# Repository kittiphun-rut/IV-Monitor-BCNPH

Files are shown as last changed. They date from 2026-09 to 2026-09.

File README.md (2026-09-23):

# IV-Monitor-BCNPH

ซอฟต์แวร์ของโครงการนวัตกรรม **Smart IV Alert** — ระบบตรวจวัดและแจ้งเตือนการให้สารน้ำทางหลอดเลือดดำ
(หอผู้ป่วยอายุรกรรม โรงพยาบาลสูงเม่น จังหวัดแพร่ / วิทยาลัยพยาบาลบรมราชชนนี แพร่)

## โครงสร้างที่เก็บ

เฟิร์มแวร์เก็บเป็น **โฟลเดอร์ชื่อคงที่สายละหนึ่ง** เลขเวอร์ชันอยู่ใน `#define APP_VERSION`
เวอร์ชันเก่าทุกตัวดูได้จาก [`VERSIONS.md`](VERSIONS.md) ซึ่งมีลิงก์โหลด zip ของทุกรุ่น

| ที่อยู่ | คำอธิบาย |
|---|---|
| `firmware/Station/` | **เฟิร์มแวร์เครื่องประจำเตียง สายหลัก** — ไม่ต้องคาลิเบรตด้วยมือ หนีบเซนเซอร์แล้วเปิดโรลเลอร์ เครื่องเรียนรู้เอง หมุนจอ 180 องศาได้ สุ่มจังหวะส่งข้อมูลกันชนกัน |
| `firmware/Station-Stable/` | **เฟิร์มแวร์เครื่องประจำเตียง สายเสถียร** — อัลกอริทึมตรวจจับเดิมพร้อมหน้าคาลิเบรต ๓ ขั้นแบบทำเอง สำหรับเครื่องที่ยังใช้วิธีเดิม |
| `firmware/Host-OLED/` | **เฟิร์มแวร์เครื่องส่วนกลาง จอ OLED** — ตรวจเลขเตียงซ้ำ หน้า LINK DIAGNOSTIC แอนิเมชันหยด หน้าเว็บ Dashboard |
| `firmware/Host-TFT28/` | **เฟิร์มแวร์เครื่องส่วนกลาง จอสี TFT 2.8"** — หน้าจอแนวทาง FOCUS + จอเตือนเต็มจอ |
| `firmware/Host-Touch24/` | **เฟิร์มแวร์เครื่องส่วนกลาง จอสัมผัส 2.4"** — ตั้งค่าได้บนจอ นาฬิกา DS3231 บันทึกลงการ์ด SD พร้อมคุณสมบัติครบเท่ารุ่นจอ OLED |
| `firmware/FlowSim-Lab/` | **เฟิร์มแวร์แบบจำลองกราฟการไหล + ทดสอบเซนเซอร์** (ไม่เชื่อมต่อ Host) — ใช้ทดลอง สาธิต และออกแบบหน้าจอ |
| `firmware/reference/` | เฟิร์มแวร์ตัวจริงที่ใช้อ้างอิง: Station v7.3.0 / v7.4.0 และ Host v4.6.0 |
| `tools/check-ino-types.py` | ตรวจว่า enum/struct ถูกประกาศก่อนจุดที่ Arduino แทรก prototype (กัน error `does not name a type`) |
| `tools/screen-preview/` | เครื่องมือเรนเดอร์ภาพหน้าจอ TFT จากไฟล์ .ino บนเครื่อง PC |
| `tools/touch-preview/` | เรนเดอร์ภาพหน้าจอของเฟิร์มแวร์ Host จอสัมผัส v4.9.0 บน PC |
| `tools/host-preview/` | เรนเดอร์ภาพหน้าจอ TFT ของเฟิร์มแวร์ Host v4.8.0-TFT บน PC |
| `tools/protocol-test/` | **ตรวจว่าโครงสร้างแพ็กเก็ต ESP-NOW ของทุกเฟิร์มแวร์ตรงกัน** (Host กับ Station ต้องตรงกันทุกไบต์) |
| `tools/oled-check/` | ตรวจว่าเฟิร์มแวร์ Host จอ OLED คอมไพล์ผ่านบน PC |
| `tools/oled-preview/` | **จำลองหน้าจอ OLED 128x64 ของ Host v4.7.4 บน PC** เรนเดอร์ออกมาเป็นภาพทุกหน้า รวมเฟรมแอนิเมชันหยด |
| `tools/host-rx-test/` | **ป้อนแพ็กเก็ตเสมือนเข้าฟังก์ชันรับของ Host บน PC** ตรวจว่า Host มองเห็นครบทุกเตียงจริงหรือไม่ (7 สถานการณ์ รวมกรณีเลขเตียงซ้ำ) |
| `tools/link-sim/` | **จำลองจังหวะเวลาของ ESP-NOW ทั้งระบบ** วัดว่าของเดิมทำให้ Host ขึ้น OFFLINE ผิดพลาดนานเท่าใด และของใหม่แก้ได้แค่ไหน |
| `tools/dashboard-preview/` | **เปิดหน้าเว็บ Dashboard บน PC พร้อมข้อมูลจำลอง** แล้วถ่ายภาพหน้าจอด้วย Chromium |
| `tools/detector-test/` | **ทดสอบอัลกอริทึมตรวจจับหยดบน PC** 10 สถานการณ์ (ถุงแกว่ง ระดับไหล สัญญาณรบกวนแรง ฯลฯ) ไม่ต้องมีบอร์ด |
| `tools/station-preview/` | เรนเดอร์ภาพทุกหน้าจอของเฟิร์มแวร์ Station v7.7.2 บน PC (มีเซนเซอร์จำลองในตัว) |
| `tools/ui-mockup/` | แบบร่าง UI ของจอ Station 3 แนวทาง (เรนเดอร์เป็นภาพเพื่อเลือกแบบก่อนลงมือเขียนจริง) |
| `hardware/` | **ผังการเชื่อมต่ออุปกรณ์ KiCad 7** ของเครื่องประจำเตียงและเครื่องศูนย์กลาง สร้างจากหมายเลขขาในเฟิร์มแวร์โดยอัตโนมัติ พร้อมสคริปต์ตรวจว่าผังตรงกับโค้ด |
| `docs/screens/` | ภาพตัวอย่างหน้าจอที่สร้างจากเครื่องมือข้างต้น |
| `docs/ui-concepts/` | ภาพเปรียบเทียบแบบร่าง UI ทั้ง 3 แนวทาง |
| `docs/screens-touch/` | ภาพหน้าจอจริงของ Host v4.9.1-TOUCH ทุกหน้า |
| `docs/ui-concepts-touch/` | แบบร่าง UI แบบสมาร์ตโฟนที่ใช้ประกอบการเลือก |
| `docs/screens-host/` | ภาพหน้าจอจริงของ Host v4.8.0-TFT ทุกหน้า |
| `docs/ui-concepts-host/` | ภาพเปรียบเทียบแบบร่าง UI ของ Host ทั้ง 3 แนวทาง |
| `docs/screens-dashboard/` | ภาพหน้าเว็บ Dashboard ที่เรนเดอร์จากเบราว์เซอร์จริง |
| `docs/screens-station/` | ภาพหน้าจอจริงของ Station v7.7.2 ทุกหน้า + ภาพเปรียบเทียบจอหมุน 180 องศา |
| `docs/คู่มือพยาบาล_Smart_IV_Alert.docx` | **คู่มือการปฏิบัติงานสำหรับพยาบาลวิชาชีพ** ตามรูปแบบเอกสารราชการไทย ๔๘ หน้า (ปก คำนำ สารบัญ ๗ บท ภาคผนวก ๕ ภาค รวมบทการติดตั้งเซนเซอร์และการคาลิเบรต) — สารบัญเป็นฟิลด์ TOC ที่อัปเดตเองได้ใน Word |
| `docs/คู่มือหน้าเว็บ_Smart_IV_Alert.docx` | **คู่มือการปฏิบัติงานเฉพาะหน้าเว็บ** ๓๐ หน้า อธิบายทุกหน้า ทุกปุ่ม และทุกบรรทัดบนการ์ดเตียง พร้อมภาพถ่ายหน้าจอจริงทั้ง ๔ หน้า |
| `docs/คู่มือพยาบาล_Smart_IV_Alert.txt` | คู่มือฉบับข้อความล้วน สำหรับคัดลอกไปใช้ต่อหรืออ่านโดยไม่ต้องมี Word |
| `docs/คู่มือพยาบาล_Smart_IV_Alert_ตัวอย่าง.pdf` | ตัวอย่าง PDF ของคู่มือ (เรนเดอร์ด้วยฟอนต์แทน ไม่ใช่ TH SarabunPSK) |
| `tools/manual-build/` | **สคริปต์สร้างคู่มือ .docx** สร้างสารบัญเป็นฟิลด์ TOC จริงพร้อมเลขหน้าที่คำนวณไว้ล่วงหน้า |
| `docs/screens-oled/` | ภาพจำลองหน้าจอ OLED ของ Host v4.7.4-OLED ทุกหน้า + เฟรมแอนิเมชันหยด |

## เริ่มต้นที่ไหน

อ่าน [`firmware/FlowSim-Lab/README.md`](firmware/FlowSim-Lab/README.md)
ซึ่งอธิบายผังหน้าจอทั้ง 3 หน้า ตารางปุ่มกด โหมดจำลอง และขั้นตอนคาลิเบรตไว้ครบ

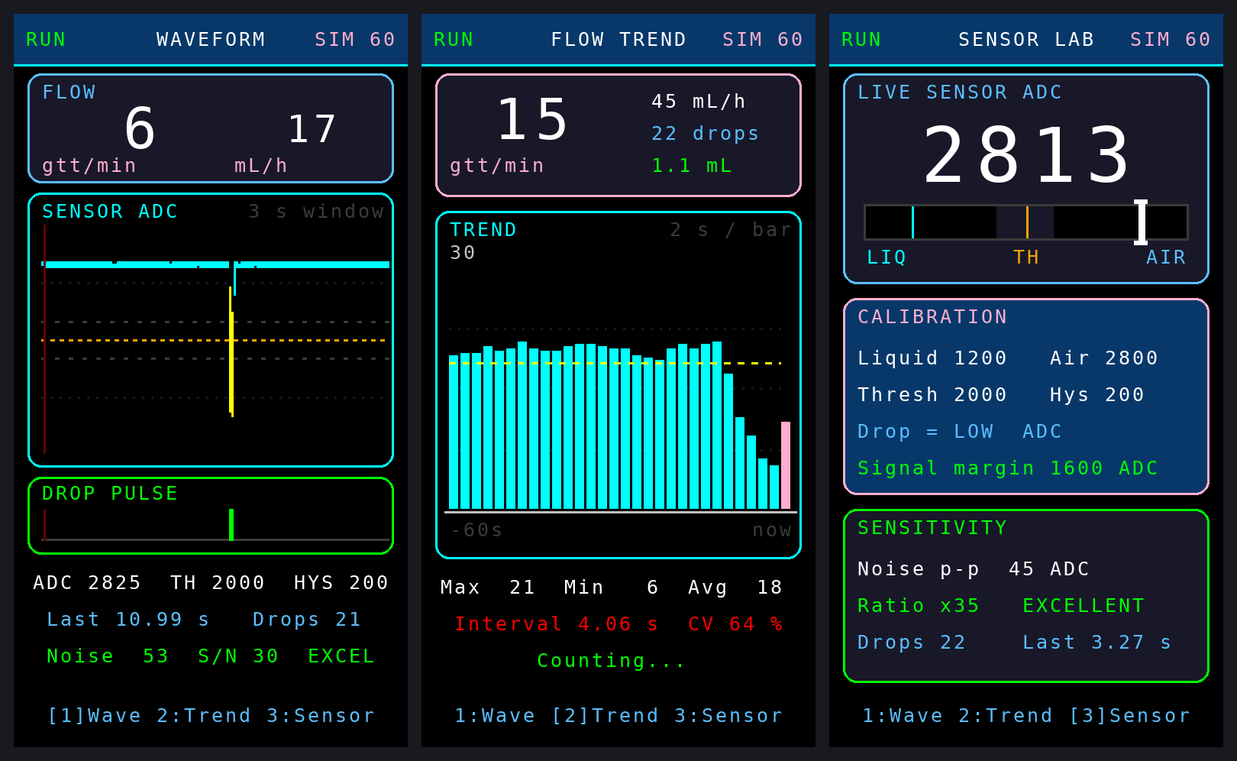
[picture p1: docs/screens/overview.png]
ภาพรวมหน้าจอ


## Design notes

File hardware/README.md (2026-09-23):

# ผังการเชื่อมต่ออุปกรณ์ (KiCad)

ผังในโฟลเดอร์นี้สร้างด้วย `tools/kicad-gen/gen_schematics.py` ซึ่ง **อ่านหมายเลขขา
GPIO จากไฟล์เฟิร์มแวร์โดยตรง ไม่ได้กรอกด้วยมือ** ถ้าย้ายขาในเฟิร์มแวร์แล้วรันสคริปต์ใหม่
ผังจะตามไปเองทันที ผังกับโค้ดจึงไม่มีทางหลุดจากกัน

```bash
python3 tools/kicad-gen/gen_schematics.py
```

| ไฟล์ | บอร์ด | อ่านขาจาก |
|---|---|---|
| `Station-BedNode.kicad_sch` | เครื่องประจำเตียง v7.7.3 | `firmware/Station/` |
| `Host-OLED.kicad_sch` | เครื่องศูนย์กลาง v4.7.5-OLED | `firmware/Host-OLED/` |

เปิดด้วย KiCad 7 ขึ้นไป (ไฟล์ `.kicad_pro` มีให้แล้ว) นิยามสัญลักษณ์ทั้งหมดฝังอยู่ในไฟล์
จึงเปิดได้บนเครื่องที่ไม่ได้ติดตั้งไลบรารีมาตรฐานของ KiCad

## ทำไมข้อความในผังเป็นภาษาอังกฤษ

KiCad 7 **ไม่รองรับการจัดวางสระและวรรณยุกต์ไทย** ทดสอบแล้วพบว่าเครื่องหมายบนและล่าง
หายทั้งหมด เช่น "อัตราการไหล" เรนเดอร์ออกมาเป็น "อตราการไหล" และ "ผู้ป่วย" เป็น "ผปวย"
ถ้าใส่ภาษาไทยลงไปจะได้เอกสารที่อ่านผิดความหมาย จึงใช้ภาษาอังกฤษในผัง (เป็นธรรมเนียม
ของงาน EDA อยู่แล้ว) และอธิบายภาษาไทยไว้ในไฟล์นี้แทน

## เครื่องประจำเตียง (Station v7.7.3)

| อุปกรณ์ | ขา ESP32-S3 | หมายเหตุ |
|---|---|---|
| จอ TFT ST7789 1.47" — SCLK | GPIO 13 | |
| จอ TFT — MOSI (SDA) | GPIO 12 | |
| จอ TFT — RST | GPIO 11 | |
| จอ TFT — DC | GPIO 10 | |
| จอ TFT — CS | GPIO 9 | |
| จอ TFT — BLK (ไฟหน้าจอ) | GPIO 8 | |
| เซนเซอร์ TCRT5000 — AO | GPIO 4 | ขา DO ไม่ได้ใช้ |
| บัซเซอร์ | GPIO 3 | ชนิด Passive ขับด้วย `tone()` |
| ปุ่มผู้ใช้ | GPIO 2 | ต่อลง GND ได้เลย |
| RGB LED (WS2812) | GPIO 48 | **อยู่บนบอร์ดแล้ว ไม่ต้องต่อเพิ่ม** |

**ข้อควรระวัง**

1. จ่ายไฟจอและเซนเซอร์ด้วย **3V3 เท่านั้น** ขา GPIO ของ ESP32-S3 ทนได้ 3.3V การต่อ 5V
   เข้าขาสัญญาณจะทำให้ชิปเสียหาย
2. ปุ่มใช้ `pinMode(INPUT_PULLUP)` จึงต่อระหว่าง GPIO กับ GND ได้เลย ไม่ต้องมีตัวต้านทาน
   พูลอัปภายนอก
3. บัซเซอร์ที่ใช้ต้องเป็นชนิด **Passive** เพราะเฟิร์มแวร์สร้างความถี่เองด้วย `tone()`
   ถ้าใช้บัซเซอร์แบบแม่เหล็กซึ่งกินกระแสสูง ให้เพิ่มทรานซิสเตอร์ NPN ขับ อย่าต่อตรงกับ GPIO
4. วงจรวัดแบตเตอรี่ฝั่ง Station **ปิดอยู่ในเฟิร์มแวร์** (`STATION_BAT_ADC_PIN = -1`)
   ผังจึงไม่ได้วาดไว้ ถ้าจะเปิดใช้ ต้องแก้ค่านี้เป็นหมายเลขขา ADC แล้วต่อตัวแบ่งแรงดัน 1:1

## เครื่องศูนย์กลาง (Host v4.7.5-OLED)

| อุปกรณ์ | ขา ESP32-S3 | หมายเหตุ |
|---|---|---|
| จอ OLED SH1106 — SDA | GPIO 8 | I2C 400 kHz |
| จอ OLED SH1106 — SCL | GPIO 9 | |
| ปุ่มเปิด-ปิด / พักเสียงเตือน | GPIO 4 | **ต้องเป็น RTC GPIO (0-21)** |
| ปุ่มเปลี่ยนหน้าจอ | GPIO 5 | |
| บัซเซอร์ | GPIO 7 | ชนิด Passive |
| วัดแรงดันแบตเตอรี่ | GPIO 1 | ผ่านตัวแบ่งแรงดัน 1:1 |

**ข้อควรระวัง**

1. ปุ่มเปิด-ปิดต้องอยู่บนขา RTC GPIO เพราะใช้ปลุกเครื่องจาก deep sleep ด้วย `ext0`
   ที่ระดับลอจิก 0 ถ้าย้ายไปขาอื่นที่ไม่ใช่ RTC GPIO เครื่องจะปลุกไม่ขึ้น
2. **R1 กับ R2 ต้องมีค่าเท่ากัน** เฟิร์มแวร์คำนวณ `(raw / 4095) × 3.3 × 2.0`
   ซึ่งตรึงอัตราส่วนไว้ที่ 1:1 แล้ว ถ้าใช้ค่าต่างกันค่าที่อ่านได้จะผิด
   แบตเตอรี่เต็มที่ 4.2V ผ่านตัวแบ่งเหลือ 2.1V ยังอยู่ในช่วงที่ ADC รับได้
3. โมดูล OLED สำเร็จรูปส่วนใหญ่มีตัวต้านทานพูลอัป I2C มาแล้ว ถ้าโมดูลที่ใช้ไม่มี
   ให้เพิ่ม 4.7kΩ จาก SDA ขึ้น 3V3 และ 4.7kΩ จาก SCL ขึ้น 3V3
4. บัสวิ่งที่ 400 kHz ตามสเปก SH1106 ควรให้สายสั้นที่สุดเท่าที่ทำได้

## การตรวจสอบ

ผังทั้งสองผ่านการตรวจด้วย `kicad-cli` เวอร์ชัน 7.0.11 โดยตรวจสองชั้น

1. **เปิดไฟล์ได้จริง** — `kicad-cli sch export pdf` สร้าง PDF สำเร็จทั้งสองไฟล์
2. **การเชื่อมต่อถูกต้อง** — `kicad-cli sch export netlist` แล้วตรวจทุกเน็ตทีละเส้น
   ว่าตรงกับ `#define` ในเฟิร์มแวร์

```bash
kicad-cli sch export pdf     --output Station-BedNode.pdf Station-BedNode.kicad_sch
kicad-cli sch export netlist --output Station-BedNode.net Station-BedNode.kicad_sch
```

## ขอบเขตที่ยังไม่ได้ทำ

* **ยังไม่มีการวางลายวงจร (PCB layout)** ผังนี้เป็นผังการเชื่อมต่ออุปกรณ์ สำหรับต่อสาย
  ระหว่างโมดูลสำเร็จรูปหรือบัดกรีบนเพอร์ฟบอร์ด ยังไม่ได้ออกแบบแผ่นวงจรพิมพ์
* **ยังไม่ได้ประกอบและทดสอบกับฮาร์ดแวร์จริง** ผังสร้างจากการอ่านโค้ด ควรตรวจทานกับ
  ซิลค์สกรีนบนบอร์ดจริงอีกครั้งก่อนบัดกรี
* **ยังไม่มีผังของ Host รุ่นจอ TFT (v4.8.0) และรุ่นจอสัมผัส (v4.9.0)** ทั้งสองรุ่นใช้ผังขา
  ต่างจากรุ่น OLED

---

# แผ่นวงจรพิมพ์ (PCB)

เป็น **บอร์ดรอง (carrier board)** สองชั้น รูทะลุทั้งหมด ไม่มีชิ้นส่วน SMD
โมดูลสำเร็จรูปทุกตัวเสียบลงหัวต่อ จึงบัดกรีด้วยมือได้และถอดเปลี่ยนโมดูลที่เสียได้

```bash
python3 tools/kicad-gen/gen_pcb.py     # สร้างบอร์ดใหม่จากหมายเลขขาในเฟิร์มแวร์
bash hardware/verify_pcb.sh            # รัน DRC จริงแล้วรายงานเฉพาะระดับ error
```

| ไฟล์ | คือ |
|---|---|
| `Station-BedNode.kicad_pcb` | บอร์ดเครื่องประจำเตียง ขนาด ๑๐๐ x ๘๖ มม. |
| `Host-OLED.kicad_pcb` | บอร์ดเครื่องศูนย์กลาง ขนาด ๑๐๐ x ๘๖ มม. |
| `ModuleFitCheck.kicad_pcb` / `.pdf` | **แผ่นทดสอบขนาดโมดูล ๑:๑** |
| `gerbers/<board>/` | ไฟล์สั่งผลิต Gerber + Excellon drill |
| `<board>-PCB.pdf` | ภาพบอร์ดสำหรับดูและตรวจทาน |

## ⚠ ต้องทำก่อนสั่งผลิต — ตรวจขนาดโมดูลด้วยแผ่น ๑:๑

บอร์ด ESP32-S3 Super Mini เป็นบอร์ดที่ผู้ผลิตแต่ละเจ้าทำไม่เหมือนกัน ทั้ง **จำนวนขาต่อแถว
ระยะห่างระหว่างสองแถว และลำดับว่าขาไหนคือ GPIO อะไร** ค่าที่ใช้อยู่ตอนนี้เป็นค่าตั้งต้น
ที่ **ยังไม่ได้ยืนยันกับบอร์ดจริง** ถ้าไม่ตรง บอร์ดที่สั่งมาจะเสียบโมดูลไม่ลงและใช้ไม่ได้เลย

ขั้นตอนตรวจ

1. พิมพ์ `ModuleFitCheck.pdf` โดยตั้งค่าเครื่องพิมพ์เป็น **สเกล ๑๐๐% หรือ Actual size**
   ห้ามใช้ Fit to page
2. **วัดแถบ ๑๐ มม. บนกระดาษด้วยไม้บรรทัดก่อน** ถ้าไม่ได้ ๑๐ มม. พอดี แปลว่าตั้งค่าพิมพ์ผิด
   อย่าเพิ่งใช้แผ่นนี้ตัดสิน
3. วางบอร์ด ESP32-S3 Super Mini ตัวจริงทาบลงบนรอยขาสองแถว ขาต้องลงรูพอดีทุกขา
4. เทียบชื่อ GPIO ที่พิมพ์ไว้กับซิลค์สกรีนบนโมดูลจริงทีละขา
5. ถ้าไม่ตรง ให้แก้ `MODULE` ที่หัวไฟล์ `tools/kicad-gen/gen_pcb.py` แล้วรันใหม่

```python
MODULE = dict(
    rows=8,                 # จำนวนขาต่อหนึ่งแถว
    row_pitch=15.24,        # ระยะห่างระหว่างสองแถว (มม.)
    pin_pitch=2.54,         # ระยะห่างระหว่างขาในแถวเดียวกัน (มม.)
    left=['5V', 'GND', '3V3', 'GPIO13', 'GPIO12', 'GPIO11', 'GPIO10', 'GPIO9'],
    right=['GPIO8', 'GPIO7', 'GPIO6', 'GPIO5', 'GPIO4', 'GPIO3', 'GPIO2', 'GPIO1'],
)
MODULE_VERIFIED = False     # ตั้งเป็น True เมื่อตรวจกับบอร์ดจริงแล้ว
```

ตราบใดที่ `MODULE_VERIFIED` ยังเป็น `False` บอร์ดจะพิมพ์คำเตือน
`MODULE FOOTPRINT UNVERIFIED` ไว้บนซิลค์สกรีน เพื่อกันการสั่งผลิตโดยยังไม่ได้ตรวจ

## วิธีเดินลายที่ใช้

เดินแบบ **แมนฮัตตันสองชั้น** — `F.Cu` เดินเฉพาะแนวตั้ง `B.Cu` เดินเฉพาะแนวนอน ต่อกันด้วยเวีย
ตัวสร้างบังคับเงื่อนไขสามข้อด้วยโค้ดก่อนเดินสายทุกครั้ง ถ้าข้อใดไม่ผ่านจะหยุดทันที

1. ขาที่ต้องเดินสายทุกขาบนฝั่งเดียวกันต้องห่างกันในแนว y อย่างน้อย ๑.๐ มม.
2. ทุกเส้นได้คอลัมน์ x ของตัวเอง
3. คอลัมน์ต้องอยู่ในช่องเดินสายที่ไม่มีขาอุปกรณ์

เมื่อครบสามข้อ ลายจะไม่มีทางทับกันเลยโดยโครงสร้าง ไม่ต้องพึ่งการตรวจด้วยสายตา

ลายกว้าง ๐.๔ มม. ระยะห่าง ๐.๒๕ มม. เวีย ๐.๘ มม. เจาะ ๐.๔ มม.
ค่าเหล่านี้อยู่ในเกณฑ์ที่โรงงาน PCB ราคาประหยัดทุกเจ้ารับผลิตได้

## ผลตรวจ

รัน DRC จริงผ่าน `pcbnew.WriteDRCReport()` ของ KiCad 7.0.11

| บอร์ด | error | unconnected pads | warning |
|---|---|---|---|
| Station-BedNode | **๐** | **๐** | ๑๗ |
| Host-OLED | **๐** | **๐** | ๑๙ |

warning ที่เหลือเป็นเรื่องซิลค์สกรีนซ้อนทับกันเล็กน้อย และ `lib_footprint_issues`
ซึ่งเกิดจากการโหลด footprint จากพาธไฟล์โดยตรงแทนที่จะผ่านตารางไลบรารี ทั้งสองอย่าง
ไม่กระทบการผลิตและไม่กระทบการทำงานทางไฟฟ้า

## ขอบเขตที่ยังไม่ได้ทำ

* **ยังไม่ได้สั่งผลิตและยังไม่ได้ประกอบจริง** ทุกอย่างตรวจด้วยเครื่องมือบนเครื่องเท่านั้น
* **ขนาดและผังขาของโมดูล ESP32-S3 Super Mini ยังไม่ได้ยืนยัน** ดูหัวข้อด้านบน
* ยังไม่ได้ออกแบบกล่อง ตำแหน่งรูยึด M3 ทั้งสี่มุมกำหนดไว้ห่างขอบ ๔ มม.
  ควรตรวจกับกล่องจริงก่อน
* ยังไม่มีบอร์ดของ Host รุ่นจอ TFT v4.8.0 และรุ่นจอสัมผัส v4.9.0

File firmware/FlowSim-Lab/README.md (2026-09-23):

# ESP32-S3 Flow Simulation & Sensor Lab (v S1.0.0)

เฟิร์มแวร์สำหรับ **จำลองและแสดงกราฟสถานะการไหล** บนจอ TFT ของเครื่องประจำเตียง
ดัดแปลงจาก **Station v7.3.0** โดย **ตัดการเชื่อมต่อทุกชนิดออก**
(ไม่มี Wi-Fi / ESP-NOW / Host / NTP) เหลือเฉพาะงานที่ต้องการทดลองจริง ๆ คือ

1. **การตรวจจับหยด** (drop counting)
2. **การคาลิเบรตเซนเซอร์** (calibration wizard)

และเพิ่มส่วนแสดงผลกราฟเพื่อดู **แนวโน้มการไหล** และ **ความไวของเซนเซอร์**
ใช้เป็นเครื่องมือทดสอบบนโต๊ะ สาธิตให้พยาบาล/คณะกรรมการดู และเป็นต้นแบบหน้าจอสำหรับพัฒนาต่อ

ภาพรวม 3 หน้าจอหลัก

---

## 1. ฮาร์ดแวร์และขาต่อ (เหมือนเครื่องจริงทุกขา)

| อุปกรณ์ | ขา ESP32-S3 |
|---|---|
| TFT ST7789 1.47" (172x320) | CS 9, DC 10, RST 11, MOSI 12, SCLK 13, BLK 8 |
| เซนเซอร์นับหยด (ขา AO อนาล็อก) | GPIO 4 |
| Passive buzzer | GPIO 3 |
| ปุ่มกด (ต่อลงกราวด์) | GPIO 2 (INPUT_PULLUP) |
| RGB LED บนบอร์ด | GPIO 48 |

**การคอมไพล์**: Arduino IDE / arduino-cli, บอร์ด *ESP32S3 Dev Module*, Arduino-ESP32 core 3.x
ไลบรารีที่ต้องมี: `Adafruit GFX Library`, `Adafruit ST7735 and ST7789 Library`

ค่าคาลิเบรตถูกเก็บใน Preferences **namespace เดียวกับเครื่องจริง (`st_cal`)**
จึงสลับแฟลชไปมาระหว่างเฟิร์มแวร์ทดลองกับเฟิร์มแวร์ใช้งานจริงได้โดยไม่ต้องคาลิเบรตใหม่

---

## 2. หน้าจอทั้ง 3 หน้า

### หน้า 1 — WAVEFORM (รูปคลื่นสัญญาณ)

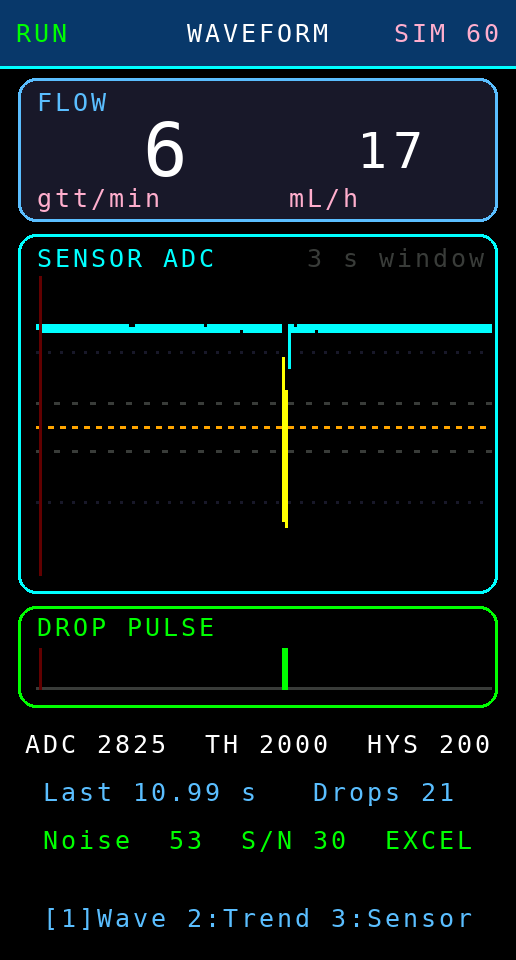
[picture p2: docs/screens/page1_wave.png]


* **กล่องบน**: อัตราไหลปัจจุบัน `gtt/min` (ตัวใหญ่) และ `mL/h`
* **กราฟรูปคลื่น**: ค่า ADC สดย้อนหลัง ~3 วินาที (152 คอลัมน์ x 20 ms)
  * เส้นสีฟ้า = สัญญาณปกติ, แท่งสีเหลือง = ช่วงที่ระบบนับว่าเป็น "หยด"
  * เส้นประสีส้ม = **เกณฑ์ตัดสิน (threshold)**
  * เส้นประสีเทาบน/ล่าง = ขอบ **ฮีสเทอรีซิส** (โซนกันสัญญาณสั่นทำให้นับซ้ำ)
  * แต่ละคอลัมน์เก็บทั้งค่าต่ำสุด-สูงสุดของช่วง จึงไม่พลาดยอดแหลมที่เกิดเร็วมาก
  * เส้นแดงเข้มที่กวาดไปทางขวา = ตำแหน่งการเขียนข้อมูลใหม่ (แบบออสซิลโลสโคป)
* **แถบ DROP PULSE**: สัญญาณดิจิทัล — แท่งเขียวคือช่วงเวลาที่เซนเซอร์ "เห็นหยด"
  ใช้ดูว่าหยดกว้างพอให้ระบบนับหรือไม่
* **3 บรรทัดล่าง**: ค่า ADC สด / threshold / hysteresis, เวลาห่างหยดล่าสุด, จำนวนหยด,
  สัญญาณรบกวน (Noise) และอัตราส่วนสัญญาณต่อสัญญาณรบกวน (S/N) พร้อมคำตัดสินความไว

### หน้า 2 — FLOW TREND (กราฟแท่งแนวโน้ม)

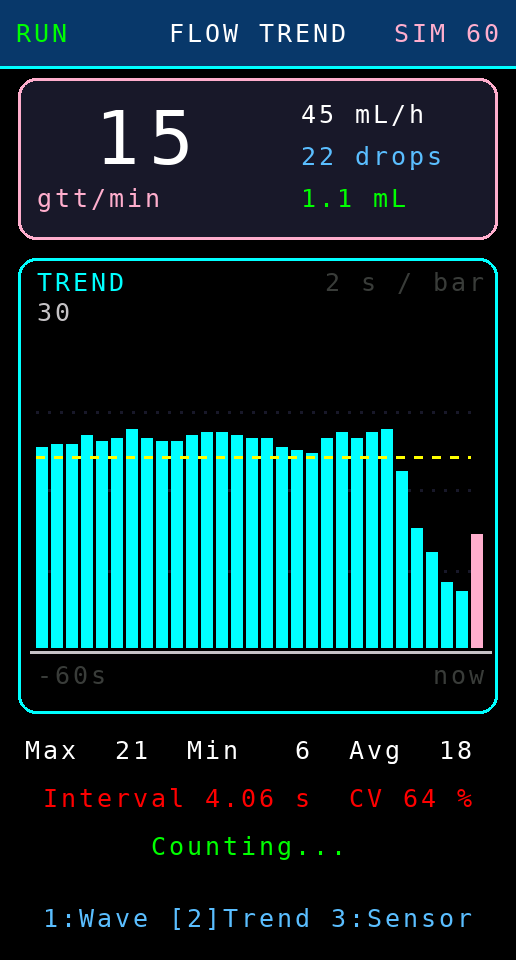
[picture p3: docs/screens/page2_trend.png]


* กราฟแท่ง 30 แท่ง แท่งละ 2 วินาที = ดูย้อนหลัง **60 วินาที**
  * แท่งฟ้า = ช่วงที่ปิดแล้ว, แท่งชมพูขวาสุด = ช่วงที่กำลังวัดอยู่
  * เส้นประเหลือง = ค่าเฉลี่ยของหน้าต่างเวลา
  * ขีดแดงที่ฐาน = ช่วงที่ไม่มีการไหลเลย
  * ตัวเลขมุมซ้ายบนของกราฟคือค่าสูงสุดของแกนตั้ง (ปรับสเกลอัตโนมัติ)
* สรุปด้านล่าง: Max / Min / Avg, ระยะห่างหยดเฉลี่ยและ **CV %**
  (ค่าความผันผวน ยิ่งน้อยยิ่งไหลสม่ำเสมอ — เขียว ≤10%, ส้ม ≤25%, แดง >25%)

### หน้า 3 — SENSOR LAB (คาลิเบรตและความไว)

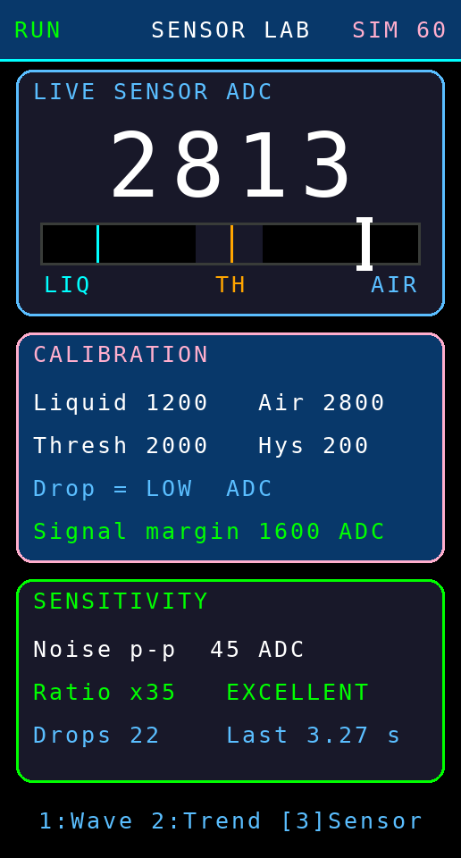
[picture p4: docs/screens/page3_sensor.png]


* ค่า ADC สดตัวใหญ่ + **เกจตำแหน่งสัญญาณ**: ขีดฟ้า = ค่าตอนมีสารน้ำ, ขีดน้ำเงิน = ตอนเป็นอากาศ,
  ขีดส้ม = เกณฑ์ตัดสิน, แถบเทา = โซนฮีสเทอรีซิส, ขีดขาว = ค่าปัจจุบัน
  (ถ้าขีดขาววิ่งข้ามขีดส้มทุกครั้งที่หยดผ่าน แปลว่าตั้งค่าได้ดี)
* กล่อง CALIBRATION: ค่าอ้างอิงที่บันทึกไว้ ทิศทางของสัญญาณ และ **Signal margin**
* กล่อง SENSITIVITY: สัญญาณรบกวนของเส้นฐาน, อัตราส่วน S/N และคำตัดสิน
  `EXCELLENT ≥20 / GOOD ≥10 / FAIR ≥5 / POOR <5`

---

## 3. ปุ่มกดเดียว ทำได้ทุกคำสั่ง

| การกด | ผลลัพธ์ |
|---|---|
| คลิก 1 ครั้ง | เปลี่ยนหน้า (WAVE → TREND → SENSOR) |
| คลิก 2 ครั้ง | RUN / HOLD (พักการนับชั่วคราว) |
| คลิก 3 ครั้ง | ล้างสถิติทั้งหมด (จำนวนหยด กราฟ ค่าเฉลี่ย) |
| คลิก 4 ครั้ง | เปิด/ปิดโหมดจำลอง และเลือกอัตรา 30 → 60 → 120 → 180 mL/h → ปิด |
| กดค้าง 3 วินาที | เข้า Calibration Wizard |
| กดค้าง 5 วินาที | หน้าวิธีใช้ / ผู้พัฒนา |

ไฟ LED: เขียว = นับปกติ, ม่วง = โหมดจำลอง, เหลือง = พักการนับ, แดง = ไม่มีการไหล,
กะพริบเขียวสว่าง 1 ครั้ง = นับได้ 1 หยด (มีเสียงติ๊กสั้นด้วย ปิดได้ที่ `SOUND_ON_DROP`)

---

## 4. โหมดจำลอง (SIM)

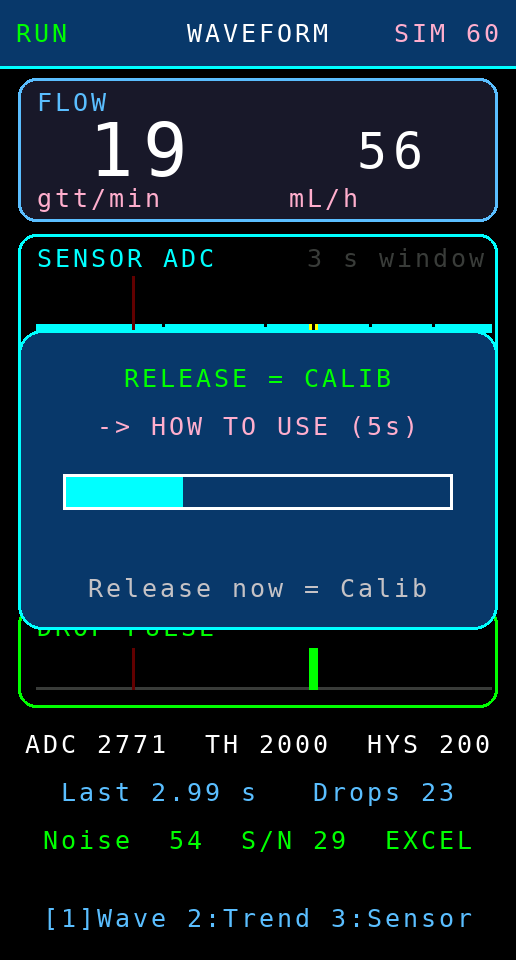
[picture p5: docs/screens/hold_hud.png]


เมื่อเปิดโหมดจำลอง เฟิร์มแวร์จะ **สร้างสัญญาณเซนเซอร์สังเคราะห์** ขึ้นมาแทนการอ่าน ADC จริง:

* รูปหยดเป็นเส้นโค้งครึ่งไซน์กว้าง 45 ms จากค่าอากาศไปหาค่าสารน้ำ
* มีสัญญาณรบกวนสุ่มประมาณ ±2% ของช่วงสัญญาณ
* จังหวะหยดตามอัตราที่เลือก บวกความคลาดเคลื่อนสุ่ม ±8%
* ทุก ๆ 20 หยดจะ **จำลองภาวะหยุดไหล** 8 วินาที เพื่อให้เห็นกราฟตกและสถานะ `NOFLOW`

ค่าที่สร้างขึ้นถูกส่งเข้าเส้นทางตรวจจับชุดเดียวกับของจริงทุกขั้นตอน
(threshold → hysteresis → debounce → คำนวณอัตราไหล) จึงใช้ทดสอบหน้าจอและตรรกะได้เสมือนจริง
โดยไม่ต้องต่อเซนเซอร์ **แต่คาลิเบรตไม่ได้** — ต้องปิดโหมดจำลองก่อน (เครื่องจะเตือนให้เอง)

---

## 5. Calibration Wizard

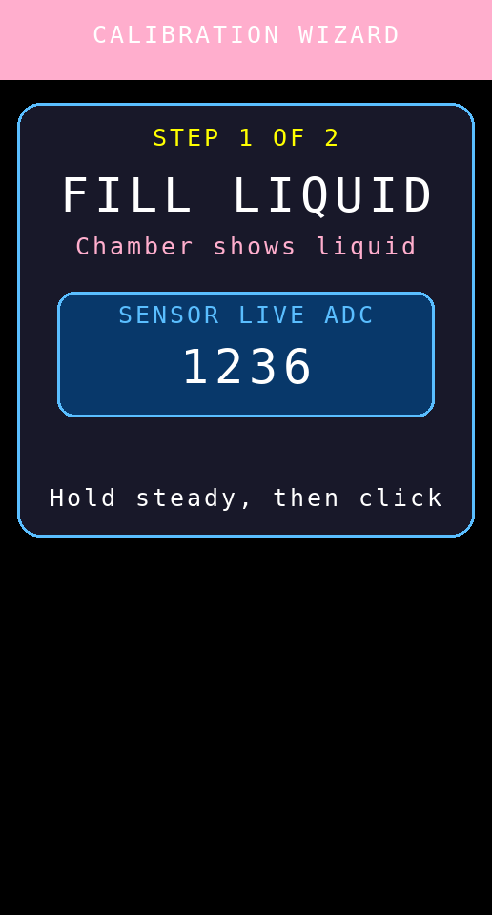
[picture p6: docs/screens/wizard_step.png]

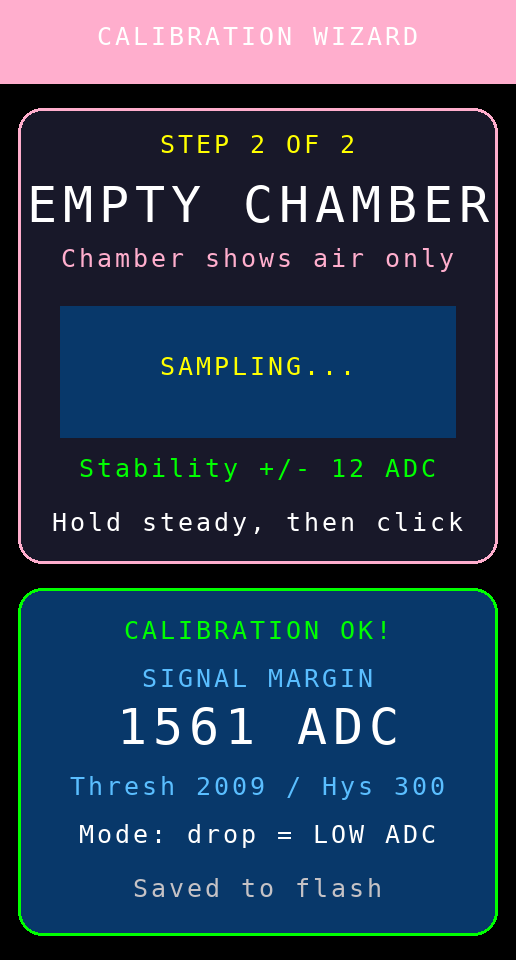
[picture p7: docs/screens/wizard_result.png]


1. **STEP 1** ให้กระเปาะมีสารน้ำ → ค้างให้นิ่ง (ดูบรรทัด `Stability +/-` ให้เป็นสีเขียว) → คลิก
2. **STEP 2** ให้กระเปาะว่าง → คลิก
3. ระบบเฉลี่ย 50 ตัวอย่างต่อจุด แล้วคำนวณ
   * `threshold = (liquid + air) / 2`
   * `hysteresis = 20% ของ margin` (จำกัดไว้ 60–300)
   * ทิศทางสัญญาณอัตโนมัติ (รองรับเซนเซอร์ทั้งสองขั้ว)
4. ถ้า margin < 80 ADC จะไม่บันทึก และคงค่าเดิมไว้

---

## 6. พารามิเตอร์ที่ปรับได้บ่อย (ต้นไฟล์ .ino)

| ค่า | ความหมาย | ค่าเริ่มต้น |
|---|---|---|
| `DROP_FACTOR` | gtt/mL ของชุดให้สารน้ำที่ใช้ทดลอง | 20 |
| `MIN_DROP_INTERVAL` | เวลากันนับซ้ำ (ms) | 55 |
| `SOUND_ON_DROP` | เสียงติ๊กทุกหยด | true |
| `WAVE_BUCKET_MS` | เวลาต่อ 1 คอลัมน์ของกราฟคลื่น (ยิ่งน้อยยิ่งละเอียด แต่หน้าต่างเวลาสั้นลง) | 20 |
| `TREND_BIN_MS` | เวลาต่อ 1 แท่งของกราฟแนวโน้ม | 2000 |
| `SIM_RATES` | อัตราของโหมดจำลอง (mL/h) | 30/60/120/180 |

---

## 7. ข้อควรทราบสำหรับการพัฒนาต่อ

* **ฟอนต์**: ใช้ฟอนต์มาตรฐานของ Adafruit GFX ซึ่งไม่รองรับภาษาไทย ข้อความบนจอจึงเป็นอังกฤษทั้งหมด
  ถ้าต้องการภาษาไทยต้องฝังฟอนต์บิตแมปไทยเพิ่ม (เช่น แปลงฟอนต์เป็น GFXfont) — คำอธิบายภาษาไทย
  ในโค้ดอยู่ในคอมเมนต์เท่านั้น
* **ภาระของ SPI**: กราฟคลื่นวาดทีละ 1 คอลัมน์ต่อ 20 ms ไม่ใช่ล้างทั้งกราฟ จึงไม่แย่งเวลาจนพลาดหยด
  หากเพิ่มกราฟใหม่ ควรยึดหลักเดียวกัน (วาดเฉพาะส่วนที่เปลี่ยน + ใช้ข้อความความกว้างคงที่เขียนทับ)
* **การย้ายกราฟกลับไปใช้ในเครื่องจริง**: ฟังก์ชันชุด `drawWaveColumn* / drawPulseColumn /
  drawTrendChart / drawSensorGauge` ไม่ผูกกับตัวแปรของ Host เลย ยกไปวางในเฟิร์มแวร์ v7.3.0
  เป็นหน้าที่ 4 ได้ทันที เพียงส่งค่า ADC และ `dropState` เข้าไป
* **พรีวิวหน้าจอบน PC**: ดู `tools/screen-preview/` — คอมไพล์สเก็ตช์ด้วย Arduino API จำลอง
  แล้วเรนเดอร์ภาพ PNG ออกมา ใช้ตรวจผังหน้าจอก่อนแฟลชจริง

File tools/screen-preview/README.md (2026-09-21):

# Screen Preview — พรีวิวหน้าจอ TFT บนเครื่อง PC

เครื่องมือเล็ก ๆ สำหรับดูผลหน้าจอ **จากไฟล์ .ino ตัวจริง** โดยไม่ต้องแฟลชลงบอร์ด
ช่วยให้ตรวจผังหน้าจอ ตัวอักษรล้นกรอบ หรือสีที่อ่านยาก ได้ตั้งแต่ก่อนขึ้นฮาร์ดแวร์

```bash
./run.sh                 # ผลลัพธ์ไปที่ docs/screens/
./run.sh /tmp/myscreens  # หรือระบุปลายทางเอง
```

ต้องมี: `g++` (C++17) และ `python3` + `pillow` (`pip install pillow`)

## หลักการทำงาน

1. `Arduino.h`, `Adafruit_GFX.h`, `Adafruit_ST7789.h`, `SPI.h`, `Preferences.h` ในโฟลเดอร์นี้
   เป็น **API จำลอง** ฝั่ง PC โดย GFX จะไม่วาดจริงแต่บันทึกคำสั่งวาดทุกคำสั่งลงไฟล์ข้อความ
2. `driver.cpp` `#include` ตัวสเก็ตช์เข้ามาตรง ๆ แล้วเดินเวลาเสมือน ~85 วินาที
   (เปิดโหมดจำลอง 60 mL/h ให้มีข้อมูลกราฟ) จากนั้นสั่งเปิดทีละหน้าและทำเครื่องหมายจุดที่ต้องการภาพ
3. `render.py` อ่านคำสั่งวาดมาประกอบเป็นภาพ PNG ขนาด 172x320 (ขยาย 3 เท่า)

## ข้อจำกัด

* ตัวอักษรเรนเดอร์ด้วยฟอนต์ DejaVu Sans Mono ให้ *ใกล้เคียง* ฟอนต์ 5x7 ของ Adafruit GFX
  ตำแหน่ง/ความกว้างต่อตัวอักษรตรงกับของจริง (6 x 8 พิกเซลต่อตัวที่ size 1) แต่รูปทรงตัวอักษรต่างกันเล็กน้อย
* มุมโค้งของกรอบและเส้นทแยงมุมเป็นการประมาณด้วย PIL
* ใช้ตรวจ "ผัง" ได้แม่นยำ แต่การตัดสินเรื่องสีจริงบนจอควรยืนยันกับฮาร์ดแวร์อีกครั้ง

## ตรวจการวาดล้นขอบจอ

ไฟล์ `ops.txt` ที่สร้างระหว่างทางสามารถนำไปตรวจพิกัดได้ เช่น หาคำสั่งที่ออกนอกกรอบ 172x320
(ดูตัวอย่างสคริปต์สั้น ๆ ในประวัติการพัฒนา หรือเขียนเพิ่มได้ตามต้องการ)

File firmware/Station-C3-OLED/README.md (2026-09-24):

# Bed Station Node v1.0.0-C3 — บอร์ดเล็ก ESP32-C3 + จอ OLED 0.42"

เครื่องประจำเตียงอีกแบบหนึ่ง ใช้บอร์ด **ESP32-C3 Super Mini** กับจอ **SSD1306 ขนาด 0.42 นิ้ว
ความละเอียด 72x40** ต่างจากสายหลักที่ใช้ ESP32-S3 กับจอ TFT สี

ปรับปรุงจากไฟล์ `ESP32-C3-Station-V_4_4_2.ino` ที่มีอยู่เดิม ให้เข้ากับระบบรุ่นปัจจุบัน

## ทำไมของเดิมใช้กับระบบรุ่นนี้ไม่ได้

**คุยกับ Host รุ่นปัจจุบันไม่ได้เลย** เพราะโครงสร้างแพ็กเก็ตคนละแบบ

| | ของเดิม v4.4.2 | Protocol v3 (รุ่นนี้) |
|---|---|---|
| `struct_message` | 14 ไบต์ | **23 ไบต์** |
| ข้อมูลที่ส่ง | ไม่มี `flowRateHr`, `msSinceLastDrop`, `flags` | ครบ |
| แพ็กเก็ตจาก Host | `struct_time_sync` 5 ไบต์ (มีแค่เวลา) | **`struct_host_sync` 20 ไบต์** |
| รับจาก Host ได้ | เวลาอย่างเดียว | เวลา, เป้าหมาย, ปริมาตรตามแผน, รหัสเตือน, drop factor, สั่งเริ่มถุงใหม่ |

Host จะเห็นเครื่องนี้เป็น OFFLINE ตลอด เพราะความยาวแพ็กเก็ตไม่ตรง จึงถูกทิ้งตั้งแต่ต้น

## สิ่งที่แก้ เรียงตามความสำคัญ

### 1. โครงสร้างแพ็กเก็ตเป็น Protocol v3

มี `static_assert` ตรึงขนาดไว้ที่ 23 และ 20 ไบต์ คอมไพล์ไม่ผ่านทันทีถ้ามีใครแก้จนเพี้ยน
และ `bash tools/protocol-test/run.sh` ตรวจซ้ำอีกชั้นว่าตรงกับทุกเฟิร์มแวร์ในโครงการ

ผลพลอยได้คือ **drop factor มาจาก Host** ตามแผนการรักษาจริง ของเดิมตรึงไว้ที่ 20 ในโค้ด

### 2. การหาช่องสัญญาณ — ข้อนี้ทำให้ของเดิมใช้ไม่ได้ตั้งแต่ Host v4.7.6

ของเดิมสแกนหาชื่อ Wi-Fi `ESP32_Liquid_Monitor` **ครั้งเดียวตอนบูต** แล้วตรึงช่องไว้

```cpp
currentChannel = findHostChannel();          // ของเดิม เรียกครั้งเดียว
esp_wifi_set_channel(currentChannel, ...);
```

ตั้งแต่ Host v4.7.6 เป็นต้นไป Host เกาะเราเตอร์ของโรงพยาบาลเป็นหลักและ **ปิด Access Point ทิ้ง**
ชื่อ Wi-Fi นั้นจึงไม่มีให้สแกนอีกแล้ว และช่องสัญญาณเป็นของเราเตอร์ ไม่ใช่ช่อง 1

รุ่นนี้ใช้ `manageChannelHunting()` แบบเดียวกับสายหลัก — ไล่ช่อง 1 ถึง 13 ช่องละ 2.5 วินาที
เมื่อไม่ได้ยิน Host แล้วจำช่องที่เจอลง NVS อย่างช้าที่สุด **32.5 วินาที** ก็กลับมาออนไลน์

### 3. เสียงออดไม่บล็อกลูปอีกต่อไป

ของเดิมใช้ `delay()` ระหว่างส่งเสียง ลูปทั้งเครื่องหยุดเดิน ตรวจจับหยดไม่ทัน
เสียงยืนยันตอนคาลิเบรตของเดิมยาวถึง 800 ms หมายถึงหยดที่ตกในช่วงนั้นหายไปเลย

รุ่นนี้เป็นคิวจังหวะ สั่ง `beepPattern(3, 90, 70)` แล้วกลับมาทำงานต่อทันที
มี `serviceBeep()` ในลูปคอยเปิดปิดออดตามเวลา

### 4. สูตรอัตราการไหล

ของเดิมนับหยดในหน้าต่าง 2.5 วินาทีแล้วคูณขึ้นเป็นต่อนาที

```cpp
currentGttMin = (dropsInLastWindow / intervalSec) * 60.0;   // ของเดิม
```

ที่อัตรา 20 หยดต่อนาที หน้าต่าง 2.5 วินาทีมีหยดเฉลี่ยไม่ถึงหนึ่งหยด ตัวเลขบนจอจึงกระโดด
ระหว่าง 0 กับ 24 กับ 48 ตลอดเวลา อ่านไม่ได้

รุ่นนี้ใช้หน้าต่างสะสม 8 หยดแบบเดียวกับสายหลัก วัดช่วงเวลาที่ครอบหลายหยดแล้วหารครั้งเดียว
(เหตุผลเชิงสถิติอยู่ในหัวข้อ "หน้าต่างคำนวณอัตราไหล" ในไฟล์ `.ino`)

### 5. ตัวตรวจจับหยดตัวเดียวกับสายหลัก

ใช้ `drop_detector.h` ซึ่งเป็นไฟล์เดียวกันทุกไบต์กับ `firmware/Station/`
เรียนรู้รูปคลื่นเองไม่ต้องคาลิเบรตด้วยมือ และตัดการแกว่งของถุงตอนคนไข้เดินออกได้

ของเดิมใช้เกณฑ์คงที่กับฮิสเทอรีซิส ซึ่งถุงแกว่งก็นับเป็นหยด และต้องคาลิเบรตสองขั้นทุกครั้ง

### 6. ตั้งเลขเตียงที่หน้าเครื่อง

ของเดิมต้องแก้ `#define STATION_ID` แล้วคอมไพล์ใหม่ทีละเตียง ใช้จริงในหอผู้ป่วยไม่ไหว
รุ่นนี้กดปุ่มค้าง 4 วินาทีเข้าหน้าตั้งเลข กดสั้นเพิ่มเลข กดค้างบันทึกลง NVS

## หน้าจอ 72x40 ออกแบบใหม่ทั้งหมด

จอนี้เล็กมาก วางตัวอักษร 4x6 ได้ 18 ตัวต่อบรรทัด และราว 5 บรรทัดเท่านั้น
จึงใช้หลักสามข้อ (รายละเอียดอยู่ในหัวไฟล์ `StationScreen.h`)

1. **หนึ่งหน้าจอ หนึ่งคำตอบ** ตัวเลขที่ตอบคำถามนั้นใช้ฟอนต์สูง 16 พิกเซล = 40% ของความสูงจอ
2. **หัวจอไม่เคยหาย** เลขเตียง สถานะการเชื่อมต่อ และนาฬิกา อยู่ครบทุกหน้า
3. **เหตุที่ต้องรีบไปดูคนไข้ กินทั้งจอ** หน้าเตือนกลับสีทั้งหน้าและกะพริบ

### หน้าที่มี

| หน้า | ตอบคำถาม | แสดง |
|---|---|---|
| RATE | ตอนนี้ไหลเท่าไร ตรงตามแผนไหม | mL/h ตัวใหญ่ · เป้าหมาย · กระเปาะหยด · แถบความคืบหน้า |
| GTT | นับหยดเทียบกับที่ตั้งไว้ตรงไหม | gtt/min ตัวใหญ่ · เป้าหมายเป็นหยดต่อนาที |
| VOLUME | ให้ไปแล้วเท่าไร นับได้กี่หยด | ปริมาตร/แผน · จำนวนหยดสะสม · สถานะเซนเซอร์ |
| STATUS | เครื่องปกติดีไหม | เลขเตียง · ช่อง · การเชื่อมต่อ · เซนเซอร์ · แบตเตอรี่ |

### กระเปาะหยด — "แสดงการนับ" ให้เห็นด้วยตา

หยดบนจอ **ล็อกกับเวลาจริงของหยดล่าสุด** ไม่ใช่อนิเมชันลอย ๆ
หยดที่เห็นบนจอจึงตกพร้อมกับหยดจริงในกระเปาะ พยาบาลใช้เทียบด้วยตาได้ว่าเครื่องนับตรงหรือไม่
ถ้าหยดหยุดเกินสามเท่าของจังหวะปกติ กระเปาะจะหยุดวาดหยด ไม่หลอกตา

### สถานะเซนเซอร์มาก่อนเป้าหมายเสมอ

ถ้าตัวตรวจจับยังเรียนรู้ไม่เสร็จ ช่องที่ปกติแสดงเป้าหมายจะขึ้นคำว่า `LEARN` แทน
เพราะระหว่างนั้นตัวเลขบนจอยังเชื่อไม่ได้ พยาบาลต้องรู้ข้อนี้ก่อน

### ปุ่มเดียว ทำได้ครบ

| การกด | ผล |
|---|---|
| กดสั้น 1 ครั้ง | เปลี่ยนหน้า (ที่หน้าเตือนใกล้หมด = กดรับทราบ ส่งกลับ Host) |
| กดสั้น 2 ครั้ง | เริ่ม / หยุดชั่วคราว |
| กดสั้น 3 ครั้ง | เข้าตัวช่วยคาลิเบรตสี่ขั้นตอน |
| กดค้าง 1.5 วินาที | กลับหน้าแรก (ในตัวช่วยคาลิเบรต = ออกโดยไม่บันทึก) |
| กดค้าง 4 วินาที | เข้าหน้าตั้งเลขเตียง (ในหน้านั้น กดสั้น = เพิ่มเลข กดค้าง = บันทึก) |

### ตัวช่วยคาลิเบรตสี่ขั้นตอน

ตัวตรวจจับเรียนรู้รูปคลื่นหยดเองได้อยู่แล้ว แต่เดิมมีปัญหาสองข้อ
**ไม่มีใครรู้ว่าวางเซนเซอร์ถูกตำแหน่งหรือยัง** จนกว่าจะยืนรอดูว่ามันนับหรือเปล่า
และ **สิ่งที่เรียนรู้ไว้หายทุกครั้งที่ปิดเครื่อง** เปิดมาต้องเรียนใหม่ทุกที
ทั้งสองข้อคือความล้มเหลวแบบเงียบ เพราะจอขึ้นว่าทำงานปกติทั้งที่ยังไม่นับอะไรเลย

แบ่งเป็นสี่ขั้นเพราะแต่ละขั้นตอบคำถามคนละข้อ และบอกได้ว่าต้องไปแก้ตรงไหน

| ขั้น | ต้องทำอะไรกับสาย | ผ่านเมื่อ | ตัวเลขบนจอ |
|---|---|---|---|
| 1 `BASELINE` | ปิดโรลเลอร์แคลมป์ | นิ่งต่อเนื่อง 3 วินาที ไม่มีหยดหลุด | `n` = สัญญาณรบกวน · `RAW HI`/`RAW LO` = ค่าดิบผิดปกติ |
| 2 `DIRECTION` | เปิดแคลมป์ให้หยด | เห็น 3 หยด และสรุปทิศได้ | `DROP LO` = หยดทำให้ค่าลดลง |
| 3 `LEARN` | ปล่อยให้หยดต่อไป | ครบ 10 หยด และ SNR ≥ 6 เท่า | นับหยด `n/10` |
| 4 `VERIFY` | ปล่อยให้หยดต่อไป | ครบ 10 หยด ความสม่ำเสมอ ≥ 60% | นับหยด `n/10` |

ผ่านครบสี่ขั้นแล้วกดหนึ่งครั้งเพื่อบันทึกลง NVS เปิดเครื่องครั้งหน้าพร้อมนับทันที
ขั้นไหนไม่ผ่านในเวลาที่กำหนด จอจะกลับสีทั้งแถบและบอกสาเหตุเป็นสิ่งที่ลงมือแก้ได้
เช่น `check wiring` `too bright` `hold still` `too few drops` `weak signal`
แก้แล้วกดหนึ่งครั้งเพื่อลองขั้นเดิมใหม่ ไม่ต้องเริ่มจากขั้นแรก

**เวลารอของแต่ละขั้นไม่เท่ากัน** ขั้นที่ 1 ให้ 20 วินาที ขั้นที่ต้องรอหยดให้ 180 วินาที
เพราะจำนวนหยดขึ้นกับอัตราการไหลของผู้ป่วย ที่ 20 mL/h กับ drop factor 20
คือ 9 วินาทีต่อหยด สิบหยดใช้เวลาราว 90 วินาที

**ขั้นที่ 2 วัดทิศสัญญาณเอง ไม่ได้รออ่านผลจากตัวตรวจจับ** เพราะกลไกหาทิศในตัว
`drop_detector.h` เป็นการลองผิดลองถูก ให้เวลาทิศละ 10 วินาที ครบแล้วยังจับจังหวะ
ไม่ได้ก็สลับทิศ ที่อัตราไหลปกติกว่าจะจับจังหวะได้สม่ำเสมอต้องใช้ราว 5 หยด ซึ่งเกิน
10 วินาที มันจึงสลับไปทิศที่ผิดแล้วล็อกทิศนั้นไว้ ตัวเลขยังนับได้เพราะไปเกาะไหล่ของ
พัลส์แทนตัวพัลส์ แต่ความสูงที่วัดได้เหลือครึ่งเดียว SNR จึงตกลงครึ่งหนึ่ง
ขั้นนี้จึงเทียบค่าดิบกับค่าเฉลี่ยของตัวเองแล้วดูว่าเบี่ยงไปทางไหนมากกว่า
ได้คำตอบภายในสามหยดและไม่ขึ้นกับว่าตัวตรวจจับจะจับจังหวะได้เมื่อไร

ภาพหน้าจอทั้งแปดขั้นตอนอยู่ที่ [`docs/screens-c3/overview.png`](../../docs/screens-c3/overview.png)

## การต่อสาย

คงผังขาเดิมของบอร์ด v4.4.2 ไว้ทุกขา ไม่ต้องแก้สายที่ประกอบไว้แล้ว

| อุปกรณ์ | ขา |
|---|---|
| TCRT5000 ขา AO | GPIO 4 |
| ตัวแบ่งแรงดันแบตเตอรี่ | GPIO 0 |
| ออดแบบมีวงจรกำเนิดเสียงในตัว | GPIO 3 (สั่งงานด้วยลอจิกสูง) |
| ปุ่มกด | GPIO 7 (ต่อลงกราวด์) |
| จอ OLED I2C | SCL GPIO 6 · SDA GPIO 5 |

## ดูหน้าจอโดยไม่ต้องมีบอร์ด

```bash
bash tools/c3-preview/run.sh          # ภาพออกที่ docs/screens-c3/
```

เครื่องมือนี้ **ป้อนสัญญาณหยดสังเคราะห์เข้าตัวตรวจจับตัวจริง** ไม่ใช่ตั้งค่าสถานะลัด
ภาพที่ได้จึงสะท้อนพฤติกรรมจริงของอัลกอริทึม รวมถึงคำว่า `LEARN` ที่ขึ้นก่อนแล้วเปลี่ยนเป็น
เป้าหมายเมื่อเรียนรู้เสร็จ

## ข้อจำกัด

เฟิร์มแวร์นี้ **ยังไม่ได้ทดสอบบนฮาร์ดแวร์จริง** ตรวจด้วยเครื่องมือจำลองบน PC เท่านั้น
สิ่งที่ควรดูเป็นอันดับแรกตอนมีบอร์ดจริง

1. **แอมพลิจูดของสัญญาณ TCRT5000 บนบอร์ด C3** — ADC ของ C3 เป็นคนละตัวกับ S3
   ค่า `DetectorConfig` ที่ยกมาจากสายหลักอาจต้องปรับ
2. **เวลาที่ใช้ไล่หาช่องจริง** ค่า 32.5 วินาทีเป็นค่าคำนวณจากโค้ด ยังไม่ได้จับเวลาจริง
3. **ความคมของจอ 0.42 นิ้ว** ฟอนต์สูง 16 พิกเซลบนจอกว้าง 1 เซนติเมตรกว่า ๆ
   ต้องดูของจริงว่าพยาบาลอ่านจากปลายเตียงได้ในระยะเท่าใด

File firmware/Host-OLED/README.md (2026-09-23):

# เครื่องส่วนกลาง จอ OLED v4.7.7 — แยกโค้ดวาดจอออกเป็น `HostScreen.h`

ไฟล์หลักเดิมยาวจนหาของยาก รุ่นนี้ย้ายโค้ดที่ทำหน้าที่วาดจอทั้งหมดออกไปไว้ใน
ไฟล์ `HostScreen.h` ของสเก็ตช์เดียวกัน Arduino IDE แสดงเป็นแท็บคู่กัน เปิดพร้อมกันได้

```
ย้ายออกไป 365 บรรทัด    ไฟล์หลักเหลือ 1957 บรรทัด
```

**เป็นการย้ายที่อยู่ล้วน ๆ ไม่ได้แก้เนื้อในแม้แต่บรรทัดเดียว**
ตรรกะการวัด การแจ้งเตือน และโครงสร้างแพ็กเก็ต Protocol v3 เท่าเดิมทุกไบต์
ใช้คู่กับรุ่นเดิมของอีกฝั่งได้ทันที

## พิสูจน์อย่างไรว่าพฤติกรรมไม่เปลี่ยน

เรนเดอร์ภาพหน้าจอจากโค้ด **ก่อนแยก** และ **หลังแยก** แล้วเทียบทีละพิกเซล
ได้ผลว่าเหมือนกันทุกจุดครบทั้ง **31 ภาพ**

ก่อนหน้านี้เทียบแบบนี้ไม่ได้ เพราะตัวจำลองอ่านนาฬิกาจริงของเครื่อง
ภาพจึงเปลี่ยนทุกครั้งที่รัน รุ่นนี้ตรึงนาฬิกาไว้แล้วที่ `previewNow()`
ใน `tools/screen-preview/Arduino.h` (เปลี่ยนได้ด้วย `PREVIEW_EPOCH`)
ผลพลอยได้คือภาพใน `docs/` ไม่ขึ้นว่าถูกแก้ทุกครั้งที่รันชุดตรวจอีกต่อไป

## กฎที่ห้ามผิดเมื่อแก้ต่อ

ไฟล์ `HostScreen.h` ถูก `#include` **ท้ายไฟล์หลัก ก่อน `setup()`** ห้ามย้ายขึ้นไปบนสุด
เพราะโค้ดในนั้นใช้ตัวแปรและฟังก์ชันช่วยที่ประกาศไว้ด้านบน

ถ้าโค้ดเหนือบรรทัด `#include` เรียกฟังก์ชันที่ย้ายไปแล้ว ต้องประกาศล่วงหน้าไว้
ในไฟล์หลัก และห้ามใส่ค่าปริยายซ้ำทั้งที่ประกาศและที่นิยาม
ตรวจด้วย `bash tools/split-check/run.sh`

---

# Central Host Gateway v4.7.6-OLED — นำการเชื่อมต่อเราเตอร์กลับมา เพื่อลดภาระซีพียู

ต่อยอดจาก **Host จอ OLED v4.7.5** โครงสร้างแพ็กเก็ต (Protocol v3) เท่าเดิมทุกไบต์
ตรรกะการวัดและการแจ้งเตือนไม่เปลี่ยน ใช้คู่กับ Station รุ่นเดิมได้ทันที

## ปัญหาที่แก้ (ใหม่ใน v4.7.6)

เมื่อพยาบาลเปิดหน้าเว็บพร้อมกันหลายเครื่อง เครื่อง Host ต้องทำหน้าที่เป็น
Access Point ให้ทุกเครื่องเอง ทั้งส่ง beacon จัดการการเข้าร่วมของแต่ละเครื่อง
และกันบัฟเฟอร์ไว้ต่อเครื่อง งานเหล่านี้แย่งเวลาจากการรับสัญญาณ ESP-NOW ของเตียง

## 1. โหมดเครือข่ายใหม่ — เกาะเราเตอร์เป็นหลัก AP เป็นตัวสำรอง

```
ปกติ    Host --STA--> เราเตอร์โรงพยาบาล
        มือถือ/แท็บเล็ต --> เราเตอร์ --> Host        AP ปิด ภาระ AP = 0

สำรอง   ต่อไม่ได้ใน 15 วินาที หรือเราเตอร์หลุดเกิน 20 วินาที
        Host เปิด AP เอง พยาบาลต่อ SSID เดิมได้เหมือนทุกวัน
```

**ไม่ใช่ `WIFI_AP_STA`** ที่เปิดทั้งสองอย่างค้างไว้แบบ v4.6.0 เพราะแบบนั้น AP
ยังทำงานอยู่ ภาระไม่ได้ลดลงเลย ที่นี่ต่อเราเตอร์สำเร็จเมื่อใด AP ถูกปิดทันที

ขณะใช้ AP สำรอง จะลองกลับไปเกาะเราเตอร์ทุก 10 นาที **แต่เฉพาะตอนไม่มีใครต่อ AP อยู่**
เพราะการสลับโหมดจะตัดการเชื่อมต่อของผู้ใช้ที่กำลังดูหน้าเว็บ

## 2. ช่องสัญญาณของ ESP-NOW — ปล่อยให้เป็นของเราเตอร์

เมื่อเกาะเราเตอร์ ช่องสัญญาณถูกเราเตอร์กำหนด ไม่ใช่ช่อง 1 อีกต่อไป
**เฟิร์มแวร์นี้ไม่บังคับช่องกลับ** เพราะ Station มี `manageChannelHunting()`
ที่ไล่ช่อง 1–13 ช่องละ 2.5 วินาทีเมื่อไม่ได้ยิน Host แล้วจำช่องที่เจอลง NVS
อย่างช้าที่สุดใช้เวลา 13 × 2.5 = **32.5 วินาที** ก็กลับมาออนไลน์ครบทุกเตียง

v4.6.0 เคยเรียก `esp_wifi_set_channel(ESPNOW_CHANNEL)` **หลัง** เกาะเราเตอร์สำเร็จ
ซึ่งดึงวิทยุกลับช่อง 1 ทั้งที่เราเตอร์อยู่ช่องอื่น ลิงก์เราเตอร์จึงพังทันที
เป็นบั๊กที่ต้องไม่ทำซ้ำ และมีคอมเมนต์กำกับไว้ในโค้ดแล้ว

## 3. ปิดโหมดประหยัดพลังงานของวิทยุซ้ำสามจุด

Arduino core เรียก `esp_wifi_set_ps(WiFi.getSleep())` **ทับค่าที่เราตั้งไว้**
ตอนเกิดเหตุการณ์ `ARDUINO_EVENT_WIFI_STA_START` และค่าปริยายของ ESP32-S3 คือ
`WIFI_PS_MIN_MODEM` ผลคือตัวรับหลับเป็นช่วง ๆ แพ็กเก็ตจากเตียงมาถึงช้าเป็นวินาที

เฟิร์มแวร์นี้จึงเรียก `forceRadioAwake()` สามจุดรอบการเข้าโหมด STA —
ก่อน `WiFi.begin()` หลัง `WiFi.begin()` และอีกครั้งเมื่อเชื่อมต่อสำเร็จ

## 4. การค้นหาเครือข่ายแบบไม่บล็อก

`WiFi.scanNetworks()` แบบเดิมบล็อกราว 2 วินาที ระหว่างนั้นวิทยุกระโดดข้ามช่อง
แพ็กเก็ต ESP-NOW หายหมด รุ่นนี้ใช้ `WiFi.scanNetworks(true)` แล้วให้หน้าเว็บ
ถามผลซ้ำทุก 0.9 วินาทีจนกว่าจะเสร็จ

ขณะอยู่โหมด AP ล้วนจะสแกนไม่ได้ เฟิร์มแวร์จึงยืมอินเทอร์เฟซ STA มาชั่วคราว
(`WIFI_AP_STA`) เฉพาะช่วงสแกน แล้วคืนโหมดเดิมพร้อมผูก peer ของ ESP-NOW กลับให้ถูกต้อง

## 5. หน้าเว็บปรับจังหวะรีเฟรชตามจำนวนผู้ใช้

ของเดิมหน้าเว็บเรียก `/api/data` **ทุก 1 วินาทีต่อหนึ่งแท็บที่เปิดอยู่**
ถ้ามี 8 เครื่องเปิดพร้อมกันคือ 8 ครั้งต่อวินาที ผ่าน `WebServer` ที่ทำงานแบบบล็อก
**นี่คือภาระตัวจริง ซึ่งการย้ายไปโหมด STA ไม่ได้ลดเลย**

Host จึงนับอัตราการเรียกในหน้าต่าง 5 วินาที ประเมินจำนวนหน้าเว็บที่เปิดอยู่
แล้วส่ง `pollMs` กลับไปให้หน้าเว็บ ยืดได้ตั้งแต่ 1 ถึง 4 วินาที
และหน้าเว็บเปลี่ยนจาก `setInterval` เป็น `setTimeout` ต่อทอด คำขอจึงไม่ทับถมกันเป็นคิว
เมื่อเครือข่ายช้า (ของเดิมยิงคำขอใหม่ทุก 1 วินาทีไม่ว่าคำขอก่อนหน้าจะเสร็จหรือยัง)

## 6. จอ OLED แสดงที่อยู่ที่ต้องพิมพ์

ที่อยู่หน้าเว็บไม่ใช่ `192.168.4.1` คงที่อีกต่อไป เมื่อเกาะเราเตอร์จะเป็นเลขที่
เราเตอร์แจกให้ จอจึงต้องบอก — แสดงทั้งบน **หน้าพักจอ** (ใต้นาฬิกา) และบน
**หน้า LINK DIAGNOSTIC** โดยคำเตือนเรื่องเลขเตียงซ้ำยังมาก่อนเสมอถ้ามี

## วิธีใช้

1. เปิดหน้าเว็บ กดปุ่ม **จุดเชื่อมต่อ** มุมขวาบน
2. กด **ค้นหา** เลือกเครือข่ายของโรงพยาบาล ใส่รหัสผ่าน
3. กด **บันทึกและเชื่อมต่อ** — หน้านี้จะหลุดเพราะ AP ถูกปิด
4. ต่อมือถือกับ Wi-Fi ของโรงพยาบาล แล้วเปิดที่อยู่ใหม่ที่แสดงบนจอเครื่อง Host
5. ถ้าต้องการกลับไปใช้จุดเชื่อมต่อในตัวถาวร กด **ลืมเครือข่ายนี้**

ถ้าเชื่อมต่อไม่สำเร็จ เครื่องจะเปิด AP กลับมาเองใน 15 วินาที ไม่ต้องทำอะไร

## ข้อจำกัด

เฟิร์มแวร์นี้ **ยังไม่ได้ทดสอบบนฮาร์ดแวร์จริง** ตรวจด้วยเครื่องมือจำลองบน PC เท่านั้น
ชุดตรวจ 9 ตัวใน `tools/` ผ่านครบ และเรนเดอร์หน้าเว็บด้วย Chromium จริงแล้ว
แต่ยังไม่ได้ยืนยันกับเราเตอร์และเตียงจริงว่าการไล่หาช่องใช้เวลาเท่าใดในสนาม

---

# Central Host Gateway v4.7.5-OLED — แก้บั๊กลำดับโค้ดและหยดปลอมบนแอนิเมชัน

ต่อยอดจาก **Host จอ OLED v4.7.4** แก้ 2 จุด ส่วนอื่นไม่เปลี่ยน
โครงสร้างแพ็กเก็ต (Protocol v3) เท่าเดิมทุกไบต์ ใช้คู่กับ Station รุ่นเดิมได้ทันที

## 1. บั๊ก `oldPlan` อ่านค่าหลังเขียนทับ (ใหม่ใน v4.7.5)

ใน `handleStationConfig()` ของเดิมประกาศ `oldPlan` **ใต้** บล็อกที่เขียนค่าใหม่ไปแล้ว

```cpp
if (server.hasArg("volume")) {
  c.planVolumeMl = v;          // เขียนทับไปแล้ว
}
...
float oldPlan = c.planVolumeMl; // เพิ่งมาอ่าน = ได้ค่าใหม่
if (nearChanged || c.planVolumeMl != oldPlan) { ... }   // เป็นเท็จเสมอ
```

`oldPlan` จึงเท่ากับค่าใหม่เสมอ เงื่อนไขเทียบเป็นเท็จตลอด

**ผลทางคลินิก** เมื่อพยาบาลเปลี่ยนปริมาตรถุงอย่างเดียว (ไม่แตะ `nearpct`)
`nearEndAck` ไม่ถูกล้าง ถ้าเตือนใกล้หมดไปแล้วสำหรับถุงเดิม **ถุงใหม่จะไม่เตือนอีกเลย**

แก้โดยย้ายการอ่านค่าเดิมขึ้นไปก่อนบล็อกที่เขียนทับ

## 2. แอนิเมชันหยดวาด "หยดปลอม" ที่อัตราต่ำ (ใหม่ใน v4.7.5)

`dripPeriodMs()` ของเดิมบีบคาบไว้ที่ 20 วินาที แต่ `dripAnimPhase()` ใช้ `% period`
โดยที่ `lastDropAtMs` เปลี่ยนเฉพาะตอนมีหยดจริง

```
3 mL/h ที่ DF 20 -> คาบจริง 60 วินาที  แต่ถูกวาดทุก 20 วินาที
= หยดปลอม 2 หยดคั่นระหว่างหยดจริงทุกครั้ง
```

ขัดกับหลักการ "ล็อกเฟสกับหยดจริง" ที่เขียนไว้ในคอมเมนต์ของฟังก์ชันเอง

แก้ 2 อย่าง

* เพดานคาบเปลี่ยนจาก 20 วินาที เป็น `MAX_OCCLUSION_MS` (เลยจากนี้เตียงถูกตีเป็น
  `DRIP_ALERT` อยู่แล้ว) คาบที่ใช้วาดจึงเป็นคาบจริง
* เพิ่มการตัด เมื่อเลยกำหนดหยดถัดไปเกิน 3 เท่าของคาบ = การไหลเปลี่ยนหรือหยุด
  แต่ยังไม่ถึงเกณฑ์สายพับ ให้หยุดวาดและรอหยดจริงส่ง `msSinceLastDrop` มา resync เฟส

---

## เอกสารเดิมจากรุ่นก่อนหน้า

ต่อยอดจาก **Host จอ OLED v4.7.3** โครงสร้างแพ็กเก็ต ESP-NOW **ไม่เปลี่ยนแม้แต่ไบต์เดียว**

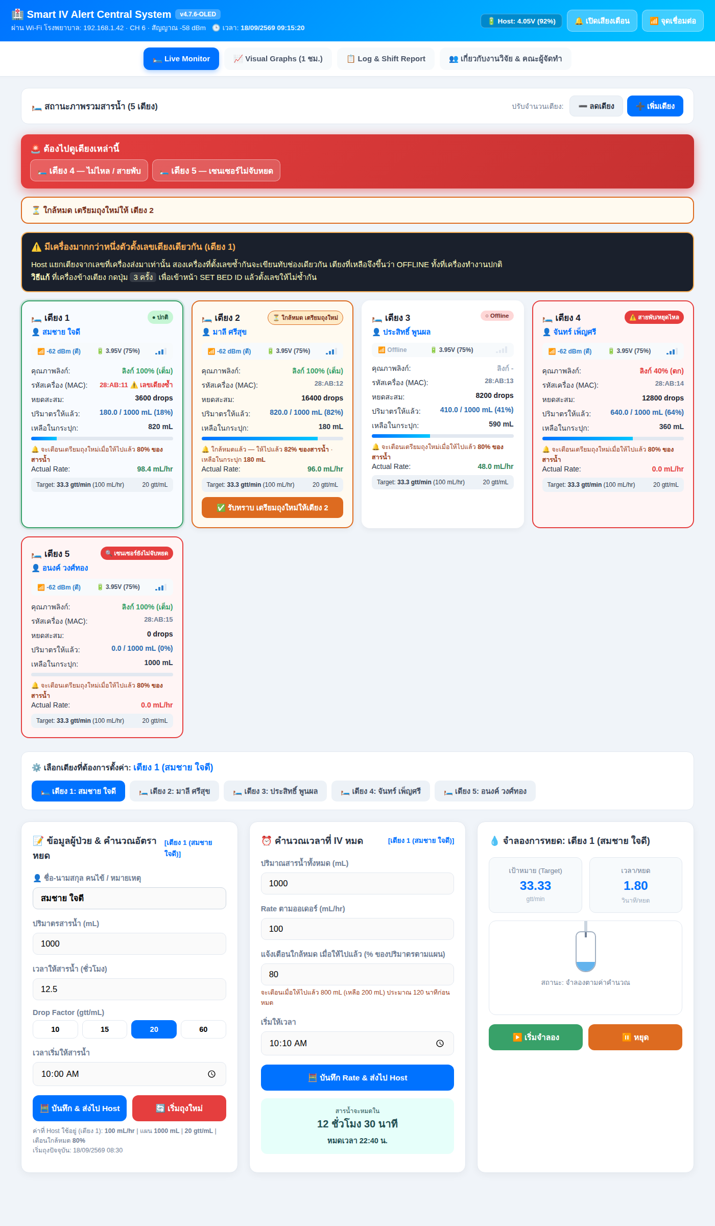
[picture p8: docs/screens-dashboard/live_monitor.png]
หน้า Live Monitor


## ทำไม v4.7.3 ยังแก้ไม่หาย

v4.7.3 แก้เรื่อง **จังหวะส่งชนกัน** ซึ่งเป็นสาเหตุหนึ่งจริง แต่ไม่ใช่สาเหตุเดียว

เวอร์ชันนี้จึงเขียนชุดทดสอบที่ **ป้อนแพ็กเก็ตเสมือนเข้าฟังก์ชันรับของ Host โดยตรง**
บนเครื่อง PC (`tools/host-rx-test/run.sh`) เพื่อพิสูจน์ว่าตรรกะรับข้อมูลถูกหรือผิด

```
ทดสอบ 1: 8 เตียง เลขเตียงไม่ซ้ำ ส่งครบทุกใบ      -> Host เห็นครบทั้ง 8 เตียง   ผ่าน
ทดสอบ 4: ตัวนับเวลา millis() ล้นรอบ               -> ยังออนไลน์ครบ             ผ่าน
```

**ตรรกะการรับของ Host ไม่ผิด** ถ้าแพ็กเก็ตมาถึงและเลขเตียงไม่ซ้ำ Host เห็นครบทุกครั้ง
ดังนั้นอาการที่เหลือมีได้แค่สามอย่าง และสองอย่างแรกคือ **ปัญหาการตั้งค่า ไม่ใช่บั๊ก**

### 1. สองเครื่องตั้งเลขเตียงซ้ำกัน  ← สาเหตุที่ตรงกับอาการที่สุด

Host แยกเตียงจาก `stationId` ในแพ็กเก็ต **เท่านั้น** ไม่ได้ดู MAC
สองเครื่องที่ตั้งเลขเดียวกันจึงเขียนทับช่องเดียวกัน เตียงที่เหลือขึ้น `OFFLINE`

และ **จอของเครื่องข้างเตียงทั้งสองตัวขึ้น ONLINE ปกติ และดึงค่าจาก Host มาแสดงได้ครบ**
เพราะทั้งคู่รับ Sync ของเลขเตียงนั้นได้เหมือนกัน — ตรงกับที่รายงานมาทุกข้อ

ชุดทดสอบจำลองอาการนี้ได้ตรง ๆ

```
ทดสอบ 5: สองบอร์ดตั้งเลขเตียงซ้ำกัน
    เตียง1 online=1  เตียง2 online=0  เตียง3 online=0
```

เครื่องทุกตัวออกจากโรงงานด้วยเลขเตียงเริ่มต้น `1` เหมือนกันหมด
(`stationPrefs.getUChar("id", 1)`) ถ้าลืมตั้งแม้เครื่องเดียวก็เกิดอาการนี้ทันที

### 2. เลขเตียงเกินจำนวนเตียงที่เปิดใช้

Host แสดงเฉพาะเตียง `1..activeStationCount` ถ้าเปิดใช้ไว้ 5 เตียง แต่มีเครื่องตั้งเลข 7
ข้อมูลของเครื่องนั้นจะถูกมองข้ามเงียบ ๆ และเตียงที่ยังไม่มีเครื่องก็ขึ้น `OFFLINE`

### 3. แพ็กเก็ตไม่มาถึงจริง (แก้ไปแล้วใน v4.7.3 + Station v7.x.x ใหม่)

## สิ่งที่เพิ่ม: ทำให้สองข้อแรกมองเห็นได้

เดิมทั้งสองกรณีนี้ **ไม่มีทางรู้เลยจากหน้าจอไหน** เวอร์ชันนี้แก้ตรงนั้น

### Host จำ MAC ของเครื่องที่ส่งมาในแต่ละเลขเตียง

```cpp
if (!s.macKnown) { memcpy(s.srcMac, src, 6); s.macKnown = true; }
else if (memcmp(s.srcMac, src, 6) != 0) {
  if (++s.idFlipCount >= ID_CONFLICT_MIN_FLIPS) s.idConflict = true;   // สลับไปมา = เลขซ้ำ
}
```

MAC ที่สลับไปมาในเลขเตียงเดียวกันแปลว่ามีมากกว่าหนึ่งเครื่องใช้เลขนั้น
(เครื่องเดิมรีบูตซ้ำ ๆ ไม่เข้าเงื่อนไข เพราะ MAC ไม่เปลี่ยน — มีทดสอบข้อ 7 คุมไว้)

### หน้า LINK DIAGNOSTIC บนจอ OLED

กดปุ่มเปลี่ยนหน้าไปจนสุดวง (ถัดจากหน้ารายละเอียดเตียงสุดท้าย)

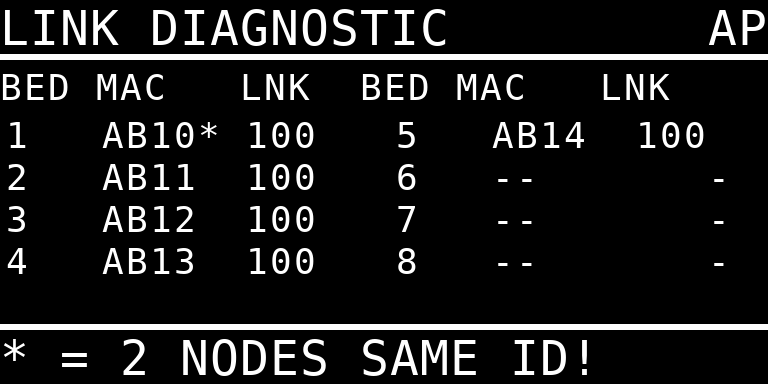
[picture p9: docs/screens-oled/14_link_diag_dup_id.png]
หน้าตรวจการเชื่อมต่อ


ตารางเลขเตียง 1-8 บอกว่าแต่ละเลข **ได้ยินจากเครื่องตัวไหน (MAC ท้าย 2 ไบต์)**
และคุณภาพลิงก์เท่าไร

* `*` ต่อท้าย MAC = เลขเตียงนี้มีมากกว่าหนึ่งเครื่องส่งมา
* แถวกลับสี = ได้ยินเลขเตียงนี้ แต่ยังไม่ได้เปิดใช้ (ต้องกดเพิ่มจำนวนเตียง)
* `--` = ไม่เคยได้ยินเลขนี้เลยในหนึ่งนาทีที่ผ่านมา

### แถบเตือนบนหน้ารวมและบนหน้าเว็บ

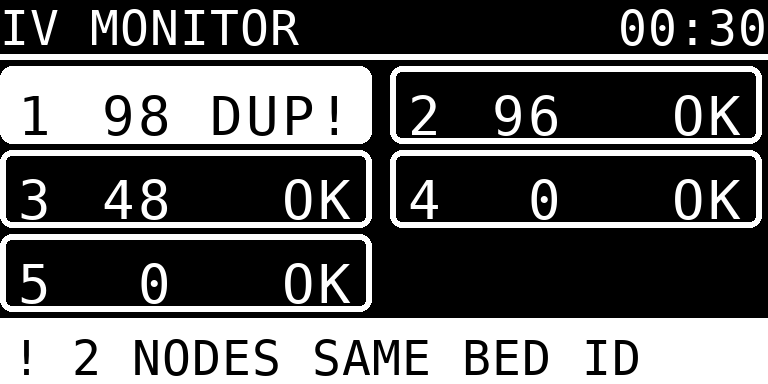
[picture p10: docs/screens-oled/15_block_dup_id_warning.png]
เตือนเลขเตียงซ้ำ


หน้าเว็บขึ้นแถบสีเข้มพร้อมวิธีแก้เป็นขั้นตอน และการ์ดของแต่ละเตียงเพิ่มแถว
**รหัสเครื่อง (MAC)** เพื่อยืนยันด้วยตาว่าทุกเตียงเป็นคนละเครื่องจริง

### ขั้นตอนตรวจเมื่อเจออาการนี้อีก

1. เปิดหน้าเว็บ ดูแถบวินิจฉัยด้านบน — ถ้าขึ้นว่าเลขซ้ำ จบ แก้ตามที่บอกได้เลย
2. ดูแถว **รหัสเครื่อง (MAC)** ของทุกเตียง ต้องไม่ซ้ำกันเลย
3. ที่เครื่องข้างเตียงแต่ละตัว กดปุ่ม **3 ครั้ง** เข้าหน้า `SET BED ID` ดูเลขให้ครบทุกตัว
4. ถ้า MAC ไม่ซ้ำและเลขไม่ซ้ำ แต่ยังขึ้น OFFLINE ให้ดูช่อง **คุณภาพลิงก์** —
   ต่ำกว่า 60% ทั้งที่ RSSI ดี แปลว่ายังมีแพ็กเก็ตชนกันอยู่

## จอ OLED: ตัดสิ่งที่มองไม่เห็นออก

จอ 128x64 ที่ติดอยู่บนผนังหรือโต๊ะพยาบาล มองจากระยะจริงแล้วฟอนต์ 4x6 อ่านไม่ออก
เวอร์ชันนี้จึงตัดองค์ประกอบที่ไม่ได้ใช้ตัดสินใจออก แล้วเอาที่ว่างไปขยายตัวอักษร

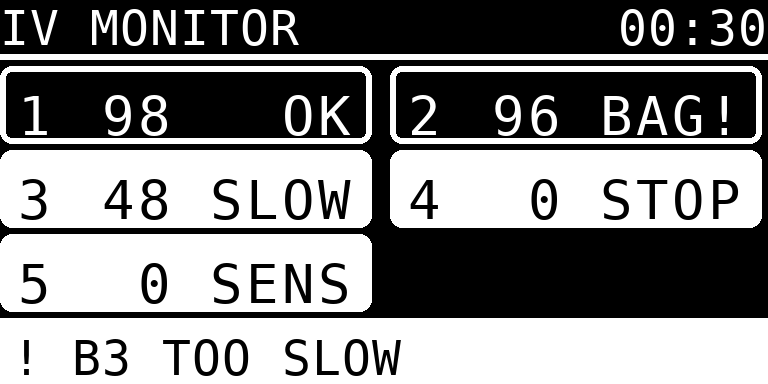
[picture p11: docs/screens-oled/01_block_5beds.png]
หน้ารวม


| เดิม (v4.7.3) | ใหม่ (v4.7.4) |
|---|---|
| `B1 [กระเปาะหยด] 98mh 180` ฟอนต์ 4x6 | `1  98 OK` ฟอนต์ 6x10 (ใหญ่ขึ้น 2.5 เท่า) |
| มีกระเปาะหยดทุกการ์ด (กว้าง 6 px มองไม่เห็นจริง) | **ย้ายไปหน้ารายละเอียดของแต่ละเตียง** ตามที่ขอ |
| มีปริมาตรสะสมในการ์ด | ตัดออก (อยู่ในหน้ารายละเอียดแล้ว) |
| เตียงวิกฤตทำป้ายเลขทึบ | **ทั้งการ์ดทึบ** เห็นได้จากท้ายห้อง |
| หัวจอ `Beds:5` ซ้ำกับแถบล่าง | เปลี่ยนเป็น **นาฬิกา** |

สามอย่างที่เหลือในการ์ดคือสิ่งที่ตัดสินใจได้ทันที — **เลขเตียง / อัตราไหล / คำสถานะ**
คำสถานะชิดขวาเสมอ ตาจึงกวาดลงเป็นแนวตั้งเพื่อหาคำผิดปกติได้

| คำ | ความหมาย | คำ | ความหมาย |
|---|---|---|---|
| `OK` | ปกติ | `STOP` | สายพับ / ไม่ไหล |
| `FAST` | ไหลเร็วเกิน | `SENS` | เซนเซอร์ยังไม่จับหยด |
| `SLOW` | ไหลช้าเกิน | `DONE` | ให้ครบตามแผนแล้ว |
| `BAG!` | ใกล้หมด ยังไม่รับทราบ | `PAUS` | พยาบาลสั่งหยุดนับ |
| `DUP!` | เลขเตียงซ้ำกับเครื่องอื่น | `OFF` | ติดต่อไม่ได้ |

### หน้ารายละเอียดของแต่ละเตียง — ที่อยู่ใหม่ของกระเปาะหยด

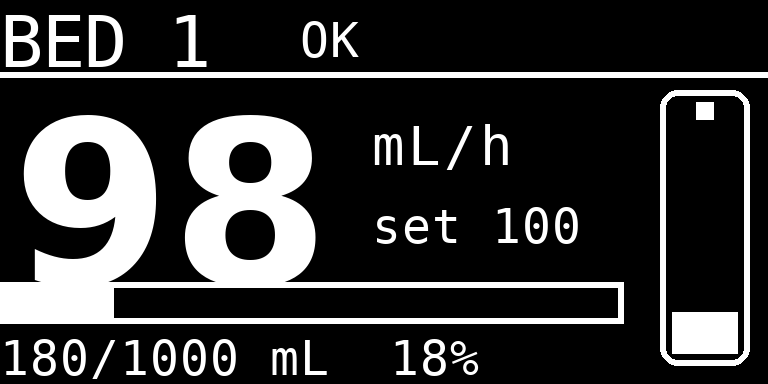
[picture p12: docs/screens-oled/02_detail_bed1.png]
หน้ารายละเอียด


* อัตราไหลเป็นตัวเลขใหญ่ที่สุดบนจอ (ฟอนต์ 32 px)
* กระเปาะหยดชิดขวา **สูง 46 px** ใหญ่พอจะเห็นหยดวิ่งจริง (เดิมในหน้ารวมกว้างแค่ 6 px)
* แถบความคืบหน้าของถุงแทนตัวเลขปริมาตรสองชุดที่อ่านยาก
* จังหวะหยดยังล็อกเฟสกับหยดจริงเหมือน v4.7.3 (`lastDropAtMs` + คาบจากอัตราไหลจริง)

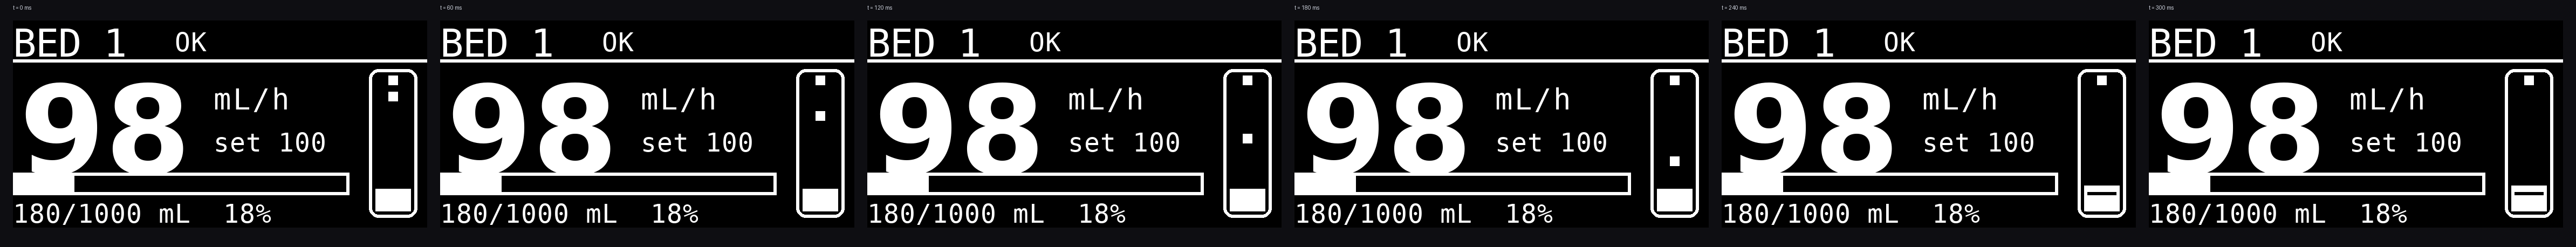
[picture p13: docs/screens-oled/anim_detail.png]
แอนิเมชันหยด


## สิ่งที่เปลี่ยนใน v4.7.2 (ยังอยู่ครบในเวอร์ชันนี้)

### 1. สถานะปกติมีกรอบสีเขียว

เดิมเตียงที่ปกติ **ไม่มีกรอบ** ทำให้แยกจากเตียงออฟไลน์ด้วยสายตายาก
ตอนนี้การ์ดของเตียงปกติมีกรอบเขียวและเงาเขียวจาง มองแวบเดียวรู้ว่าเตียงไหนเรียบร้อย

| สี | ความหมาย |
|---|---|
| 🟢 กรอบเขียว | ปกติ |
| 🟠 กรอบส้ม | ใกล้หมด เตรียมถุงใหม่ |
| 🔴 กรอบแดง + การ์ดกะพริบ | ต้องไปดูเดี๋ยวนี้ |
| ⏸️ กรอบเหลือง | หยุดนับชั่วคราว |
| ⚪ ไม่มีสี | ออฟไลน์ |

### 2. ใกล้หมดบอกเป็น % ของสารน้ำ และบอกว่าเหลือเท่าไหร่

เดิมบรรทัดเตือนเขียนว่า `เตือนเตรียมถุงใหม่ที่ 80% (800 mL)` ซึ่งตัวเลข mL
เป็นแค่ "จุดที่จะเตือน" ไม่ได้บอกว่าตอนนี้เหลือเท่าไหร่จริง ๆ

ตอนนี้

* **เพิ่มแถว `เหลือในกระปุก: N mL` ในการ์ดทุกใบ** (คำนวณจากแผนลบด้วยที่ให้ไปแล้ว)
  ตัวเลขเปลี่ยนเป็นสีส้มเมื่อเหลือไม่ถึง 100 mL
* บรรทัดเตือนเปลี่ยนเป็น
  * ยังไม่ถึงเกณฑ์ → `จะเตือนเตรียมถุงใหม่เมื่อให้ไปแล้ว 80% ของสารน้ำ`
  * ถึงเกณฑ์แล้ว → `ใกล้หมดแล้ว — ให้ไปแล้ว 82% ของสารน้ำ · เหลือในกระปุก 180 mL`

### 3. แถบแจ้งสถานะรวมบนหน้า Live Monitor

เดิมต้องกวาดตาหาว่าการ์ดใบไหนเป็นสีแดง ตอนนี้มีแถบสรุปอยู่บนสุดของหน้า
บอกชัดว่า **เตียงไหนเป็นอะไร** ครอบคลุมทั้ง 4 เหตุที่เป็นสีแดง (และเซนเซอร์ไม่จับหยด)

```
🚨 ต้องไปดูเตียงเหล่านี้
   🛏️ เตียง 3 — ไหลช้าเกิน    🛏️ เตียง 4 — ไม่ไหล / สายพับ    🛏️ เตียง 5 — เซนเซอร์ไม่จับหยด
```

และมีแถบสีส้มแยกต่างหากสำหรับเตียงที่ใกล้หมด ซึ่งเป็นเรื่อง "เฝ้าดู" ไม่ใช่เหตุวิกฤต

```
⏳ ใกล้หมด เตรียมถุงใหม่ให้ เตียง 2
```

แถบจะซ่อนเองเมื่อไม่มีเหตุ จึงไม่รบกวนสายตาตอนทุกอย่างปกติ

### 4. เสียงเตือนกระตุ้นความสนใจขึ้น

| | เดิม | ใหม่ |
|---|---|---|
| รูปคลื่น | ไซน์ (นุ่ม กลืนกับเสียงรอบข้าง) | **สี่เหลี่ยม** (ฮาร์มอนิกมาก แทรกผ่านเสียงในหอผู้ป่วยได้ดีกว่า) |
| รูปแบบ | บี๊บเดียว 880 Hz 0.5 วินาที | **4 พัลส์สลับ 1320/990 Hz** แบบเสียงรถพยาบาล |
| การขึ้นเสียง | ค่อย ๆ ดัง | ขึ้นภายใน 12 ms = สะดุดหู |
| การซ้ำ | เรียกทุกรอบ poll (ทับกันเอง) | ปล่อยเป็นชุดทุก **2 วินาที** จนกว่าเหตุจะหาย |

ปุ่ม 🔔 เปิด/ปิดเสียงเตือน ยังทำงานเหมือนเดิม และเสียงเตือนใกล้หมด (เสียงเบา 3 ครั้ง)
ไม่เปลี่ยน เพราะเป็นคนละระดับความเร่งด่วน

### 5. ป้ายเวอร์ชันอ่านค่าจริง

หัวหน้าเว็บเคยค้างอยู่ที่ `v4.6.0` ตอนนี้อ่านจาก `APP_VERSION` ที่ Host ส่งมาใน `/api/data`

## ดูหน้าเว็บโดยไม่ต้องมีบอร์ด

```bash
tools/dashboard-preview/run.sh
```

ดึง `PAGE_INDEX` ออกจาก `web_dashboard.h` ใส่ข้อมูลจำลอง 5 เตียงที่ครบทุกสถานะ
(ปกติ / ใกล้หมด / ไหลช้า / ไม่ไหล / เซนเซอร์ไม่จับหยด) แล้วถ่ายภาพหน้าจอด้วย Chromium
ใช้ตรวจหน้าตาและพฤติกรรมของ Dashboard ได้ก่อนแฟลชลงบอร์ด

## ดูหน้าจอ OLED โดยไม่ต้องมีบอร์ด

```bash
tools/oled-preview/run.sh
```

คอมไพล์เฟิร์มแวร์ตัวจริงบน PC โดยแทน U8g2 ด้วยตัวบันทึกคำสั่งวาด
แล้วเรนเดอร์กลับเป็นภาพ 128x64 ขาวดำ (ขยาย 6 เท่า) ครบทุกหน้า:
หน้าเปิดเครื่อง / หน้ารวมแบบบล็อก 1-2-5-8 เตียง / หน้ารายละเอียดเตียง /
หน้าเตียงที่เซนเซอร์ไม่จับหยด / หน้าใกล้หมด / หน้าประหยัดพลังงาน

ภาพทั้งหมดอยู่ใน [`docs/screens-oled/`](../../docs/screens-oled/)

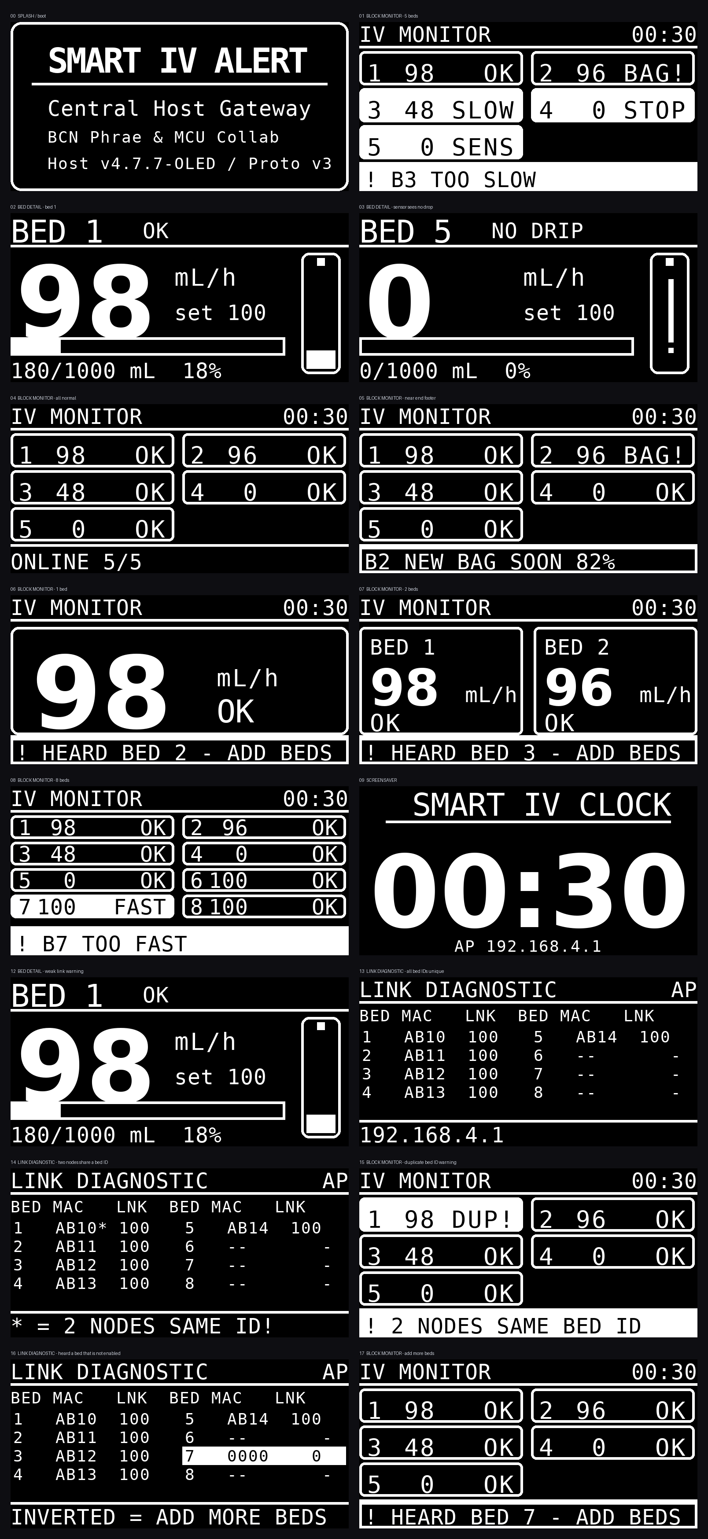
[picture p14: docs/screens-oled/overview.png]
ภาพรวมหน้าจอ OLED


ฟอนต์ความกว้างคงที่ (4x6, 5x8, 6x10, 7x13, 7x14B) เรนเดอร์ตรงตำแหน่งพิกเซลจริง
ใช้ตรวจการวางเลย์เอาต์และข้อความล้นขอบจอได้แม่นยำ ส่วนฟอนต์สัดส่วน
(helvB10/12, logisoso16/32) เป็นการประมาณขนาด — รูปทรงตัวอักษรจะไม่เหมือนของจริงเป๊ะ

## หมายเหตุ

* **ยังไม่ได้ทดสอบบนฮาร์ดแวร์จริง** เมื่อแฟลชแล้วให้ทำตาม "ขั้นตอนตรวจ" ด้านบนก่อน
  เพราะถ้าสาเหตุคือเลขเตียงซ้ำ จะเห็นผลทันทีโดยไม่ต้องแก้อะไรในโค้ดอีก
* เวอร์ชันนี้ **ไม่ได้เปลี่ยนตรรกะการรับข้อมูล** เลย เพิ่มแต่การจำ MAC และการแสดงผล
  ตรรกะเดิมผ่านชุดทดสอบทั้ง 7 ข้อใน `tools/host-rx-test/`
* v4.7.3 ยังอยู่ในที่เก็บครบถ้วนสำหรับย้อนกลับ

* ถ้าจอ OLED ภาพรวนหลังอัปเดต ให้ลด `OLED_I2C_HZ` กลับเป็น `100000`

* **ยังไม่ได้ทดสอบบนฮาร์ดแวร์จริง** — ภาพด้านบนมาจากเบราว์เซอร์จริงพร้อมข้อมูลจำลอง
  สิ่งที่ควรลองบนเครื่องจริง: เสียงเตือนดังพอในหอผู้ป่วยหรือไม่ (ปรับค่า `0.32`
  ในฟังก์ชัน `playAlarmTone()` ได้ถ้าต้องการดังขึ้น) และแถบแจ้งเตือนอ่านง่ายบนจอที่ใช้จริงไหม
* v4.7.1 ยังอยู่ในที่เก็บครบถ้วนสำหรับย้อนกลับ
* รายละเอียดการรองรับ Station v7.5.1 / v7.7.0 และการเตือน "เซนเซอร์ยังไม่จับหยด"
  อยู่ใน [README ของ v4.7.1](https://github.com/kittiphun-rut/IV-Monitor-BCNPH/blob/release/07-s7.7.0-h4.7.1/firmware/**Host จอ OLED v4.7.1**/README.md)

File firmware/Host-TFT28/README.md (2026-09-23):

# เครื่องส่วนกลาง จอ TFT 2.8" v4.8.1 — แยกโค้ดวาดจอออกเป็น `HostScreen.h`

ไฟล์หลักเดิมยาวจนหาของยาก รุ่นนี้ย้ายโค้ดที่ทำหน้าที่วาดจอทั้งหมดออกไปไว้ใน
ไฟล์ `HostScreen.h` ของสเก็ตช์เดียวกัน Arduino IDE แสดงเป็นแท็บคู่กัน เปิดพร้อมกันได้

```
ย้ายออกไป 282 บรรทัด    ไฟล์หลักเหลือ 1563 บรรทัด
```

**เป็นการย้ายที่อยู่ล้วน ๆ ไม่ได้แก้เนื้อในแม้แต่บรรทัดเดียว**
ตรรกะการวัด การแจ้งเตือน และโครงสร้างแพ็กเก็ต Protocol v3 เท่าเดิมทุกไบต์
ใช้คู่กับรุ่นเดิมของอีกฝั่งได้ทันที

## พิสูจน์อย่างไรว่าพฤติกรรมไม่เปลี่ยน

เรนเดอร์ภาพหน้าจอจากโค้ด **ก่อนแยก** และ **หลังแยก** แล้วเทียบทีละพิกเซล
ได้ผลว่าเหมือนกันทุกจุดครบทั้ง **8 ภาพ**

ก่อนหน้านี้เทียบแบบนี้ไม่ได้ เพราะตัวจำลองอ่านนาฬิกาจริงของเครื่อง
ภาพจึงเปลี่ยนทุกครั้งที่รัน รุ่นนี้ตรึงนาฬิกาไว้แล้วที่ `previewNow()`
ใน `tools/screen-preview/Arduino.h` (เปลี่ยนได้ด้วย `PREVIEW_EPOCH`)
ผลพลอยได้คือภาพใน `docs/` ไม่ขึ้นว่าถูกแก้ทุกครั้งที่รันชุดตรวจอีกต่อไป

## กฎที่ห้ามผิดเมื่อแก้ต่อ

ไฟล์ `HostScreen.h` ถูก `#include` **ท้ายไฟล์หลัก ก่อน `setup()`** ห้ามย้ายขึ้นไปบนสุด
เพราะโค้ดในนั้นใช้ตัวแปรและฟังก์ชันช่วยที่ประกาศไว้ด้านบน

ถ้าโค้ดเหนือบรรทัด `#include` เรียกฟังก์ชันที่ย้ายไปแล้ว ต้องประกาศล่วงหน้าไว้
ในไฟล์หลัก และห้ามใส่ค่าปริยายซ้ำทั้งที่ประกาศและที่นิยาม
ตรวจด้วย `bash tools/split-check/run.sh`

---

# Central Host Gateway v4.8.0-TFT — จอสี 2.8 นิ้ว (ST7789V)

ดัดแปลงจาก **Host จอ OLED v4.7.0** โดย **เปลี่ยนเฉพาะส่วนแสดงผล** จากจอ OLED 1.3" ขาวดำ
มาเป็นจอสี TFT 2.8" ความละเอียด 240x320 (ใช้แนวนอน 320x240)
ตรรกะการวัด การแจ้งเตือน ESP-NOW (Protocol v3) และหน้าเว็บทั้งหมดเหมือน v4.7.0 ทุกประการ
จึงใช้คู่กับ **Station v7.4.x / v7.5.x** ได้ทันที

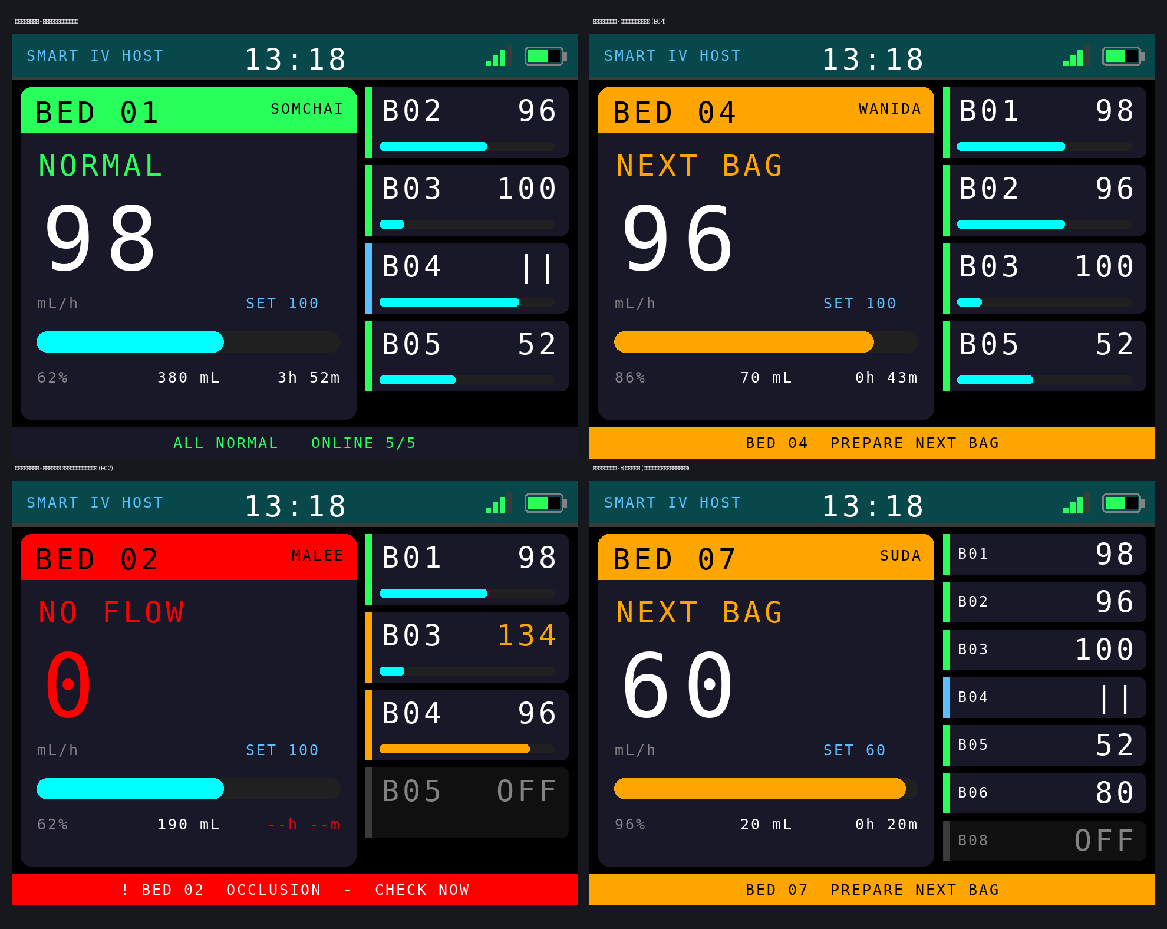
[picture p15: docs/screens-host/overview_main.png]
หน้าหลัก


## โครงสร้างไฟล์ในโฟลเดอร์นี้

| ไฟล์ | หน้าที่ | ขนาด |
|---|---|---|
| `Host-TFT28.ino` | เฟิร์มแวร์: การวัด แจ้งเตือน ESP-NOW และการแสดงผลบนจอ TFT | ~1,830 บรรทัด |
| `web_dashboard.h` | หน้าเว็บ Dashboard (HTML/CSS/JavaScript) ที่ส่งให้เบราว์เซอร์ | ~1,530 บรรทัด |

เดิมหน้าเว็บฝังอยู่ในไฟล์ .ino ทำให้ไฟล์ยาว 3,325 บรรทัด แยกออกมาแล้วเหลือ 1,826 บรรทัด
การแก้หน้าเว็บกับการแก้ตรรกะเครื่องจึงไม่ปนกัน ทั้งสองไฟล์ต้องอยู่ในโฟลเดอร์เดียวกัน
(Arduino IDE คอมไพล์ไฟล์ในโฟลเดอร์สเก็ตช์ให้อัตโนมัติ) ผลลัพธ์ที่ได้เหมือนเดิมทุกไบต์

## การต่อจอ

| ขาบนจอ TFT | ขา ESP32-S3 | หมายเหตุ |
|---|---|---|
| VCC | 3V3 | |
| GND | GND | |
| SCL / SCK | **GPIO 12** | `TFT_SCLK` |
| SDA / MOSI | **GPIO 11** | `TFT_MOSI` |
| RES | **GPIO 8** | `TFT_RST` |
| DC | **GPIO 9** | `TFT_DC` |
| CS | **GPIO 10** | `TFT_CS` |
| BLK | **GPIO 13** | `TFT_BLK` — ถ้าต่อไฟหน้าจอไว้กับ 3V3 ตลอด ให้ตั้งค่าเป็น `-1` |

* แก้เลขขาได้ที่ต้นไฟล์ (`#define TFT_CS` ...) ขาเดิมของ OLED (8, 9) ถูกนำมาใช้กับ RES/DC แล้ว
* **ห้ามใช้ GPIO 33-37** บนบอร์ด N16R8 เพราะถูกใช้กับ PSRAM
* ถ้าภาพกลับหัว ให้เปลี่ยน `#define TFT_ROTATION 1` เป็น `3`
* ไลบรารีที่ต้องติดตั้งเพิ่ม: `Adafruit GFX Library`, `Adafruit ST7735 and ST7789 Library`
  (ไม่ต้องใช้ U8g2 อีกต่อไป — เฟิร์มแวร์นี้รองรับจอ TFT อย่างเดียว ถ้าจะใช้ OLED ให้ใช้ v4.7.0)

## หน้าหลัก — แนวทาง FOCUS

* **ครึ่งซ้าย** = เตียงที่ต้องดูตอนนี้ — หมายเลขเตียง ชื่อผู้ป่วย สถานะ อัตราไหลตัวใหญ่
  อัตราเป้าหมาย แถบความคืบหน้า และแถวสรุป (% / ปริมาณคงเหลือ / เวลาที่เหลือ)
* **ครึ่งขวา** = เตียงอื่นทั้งหมด แต่ละแถวมีแถบสีสถานะ หมายเลขเตียง อัตราไหล และแถบความคืบหน้า
  ความสูงแถวปรับอัตโนมัติตามจำนวนเตียง (5 เตียงแถวใหญ่ / 8 เตียงแถวกะทัดรัด)
* **แถบล่าง** = สิ่งที่ต้องทำตอนนี้ (มีเหตุ = แดง, ใกล้หมดถุง = ส้ม, ปกติ = จำนวนเตียงที่ออนไลน์)

เตียงที่ถูกเน้นเลือกให้อัตโนมัติ: **เหตุวิกฤตมาก่อน → ใกล้หมดถุง → เตียงที่ผู้ใช้เลือกเอง**

## จอเตือนเต็มจอ และหน้าจออื่น

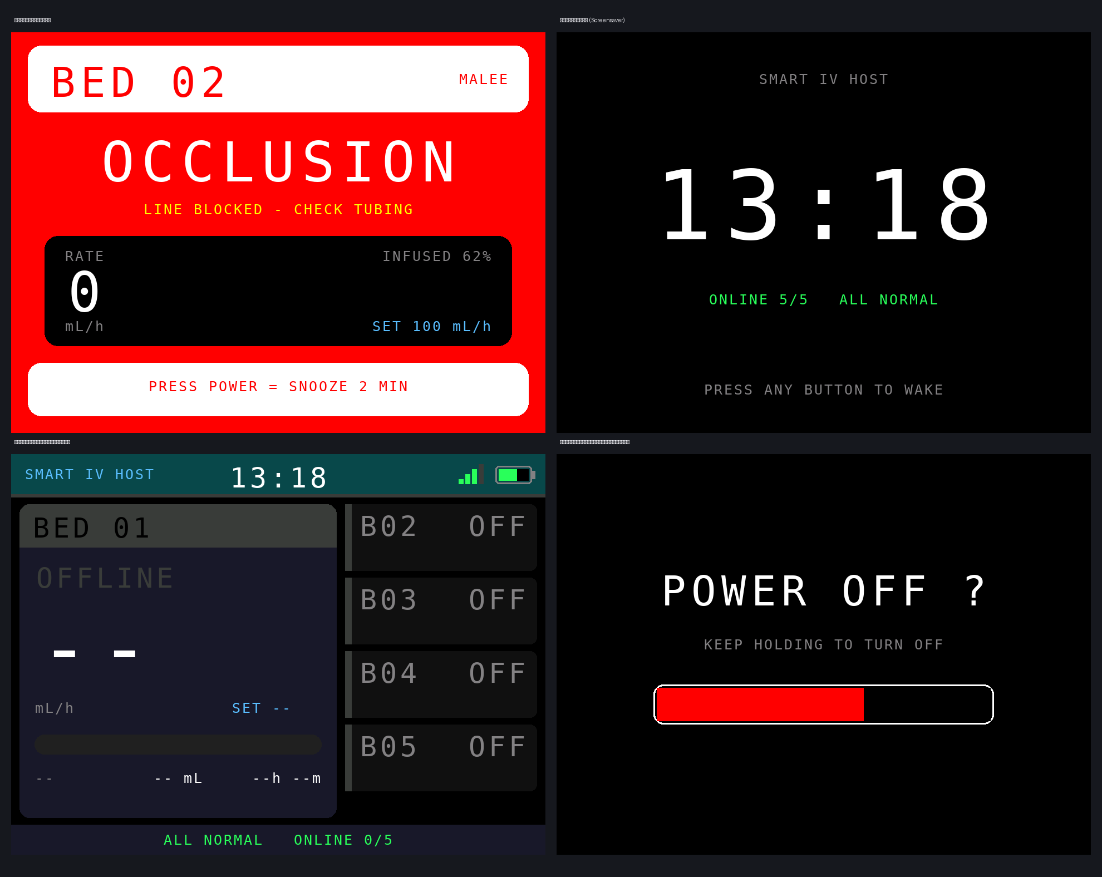
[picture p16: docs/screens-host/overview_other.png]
จอเตือนและหน้าจออื่น


จอเตือนเต็มจอสีแดงจะขึ้นเองเมื่อมีเหตุวิกฤตและยังไม่พักเสียง แสดงหมายเลขเตียง ชื่อผู้ป่วย
ชนิดของเหตุ คำแนะนำสิ่งที่ต้องตรวจ อัตราไหลจริงเทียบกับเป้าหมาย และ % ที่ให้ไปแล้ว
กดปุ่ม POWER สั้น ๆ = พักเสียง 2 นาที (กลับสู่หน้าหลักทันที)

## ปุ่มกด

| ปุ่ม | การกด | ผลลัพธ์ |
|---|---|---|
| POWER | กดสั้นขณะมีเสียงเตือน | พักเสียง 2 นาที |
| POWER | กดสั้นขณะมีเตือนใกล้หมด | รับทราบทุกเตียง (หยุดเตือนซ้ำ) |
| POWER | กดสั้นปกติ | ปิด/เปิดหน้าจอ (ดับไฟหน้าจอ ระบบยังทำงาน) |
| POWER | กดค้าง 2 วินาที | ปิดเครื่อง (Deep sleep) — กดค้าง 2 วินาทีเพื่อเปิดใหม่ |
| PAGE | คลิก 1 ครั้ง | เลื่อนดูเตียงถัดไปเอง (กลับเป็นอัตโนมัติใน 1 นาที หรือเมื่อมีเหตุใหม่) |
| PAGE | ดับเบิลคลิก | เข้าโหมดนาฬิกา (คลิกอีกครั้งเพื่อออก) |

## หมายเหตุสำหรับการพัฒนาต่อ

* ทุกหน้าจอวาดเฉพาะส่วนที่ค่าเปลี่ยน (มีตัวแปรแคชกำกับทุกชิ้น) และรีเฟรชทุก 500 ms
  จึงไม่กะพริบและไม่แย่งเวลา CPU ที่ต้องรับแพ็กเก็ต ESP-NOW ทุก 1 วินาที
* ฟอนต์มาตรฐานของ Adafruit GFX ไม่มีตัวอักษรไทย ชื่อผู้ป่วยที่ตั้งจากหน้าเว็บ
  จะแสดงได้เฉพาะอักษรโรมัน (ภาษาไทยจะกลายเป็นอักขระแปลก) — หากต้องการภาษาไทยบนจอ
  ต้องฝังฟอนต์บิตแมปไทยเพิ่ม ส่วนหน้าเว็บยังแสดงภาษาไทยได้ตามปกติ
* ดูภาพหน้าจอทุกหน้าโดยไม่ต้องแฟลชลงบอร์ดได้ที่ `tools/host-preview/run.sh`

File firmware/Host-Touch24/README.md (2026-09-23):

# เครื่องส่วนกลาง จอสัมผัส 2.4" v4.9.3 — แยกโค้ดวาดจอออกเป็น `HostScreen.h`

ไฟล์หลักเดิมยาวจนหาของยาก รุ่นนี้ย้ายโค้ดที่ทำหน้าที่วาดจอทั้งหมดออกไปไว้ใน
ไฟล์ `HostScreen.h` ของสเก็ตช์เดียวกัน Arduino IDE แสดงเป็นแท็บคู่กัน เปิดพร้อมกันได้

```
ย้ายออกไป 503 บรรทัด    ไฟล์หลักเหลือ 2582 บรรทัด
```

**เป็นการย้ายที่อยู่ล้วน ๆ ไม่ได้แก้เนื้อในแม้แต่บรรทัดเดียว**
ตรรกะการวัด การแจ้งเตือน และโครงสร้างแพ็กเก็ต Protocol v3 เท่าเดิมทุกไบต์
ใช้คู่กับรุ่นเดิมของอีกฝั่งได้ทันที

## พิสูจน์อย่างไรว่าพฤติกรรมไม่เปลี่ยน

เรนเดอร์ภาพหน้าจอจากโค้ด **ก่อนแยก** และ **หลังแยก** แล้วเทียบทีละพิกเซล
ได้ผลว่าเหมือนกันทุกจุดครบทั้ง **12 ภาพ**

ก่อนหน้านี้เทียบแบบนี้ไม่ได้ เพราะตัวจำลองอ่านนาฬิกาจริงของเครื่อง
ภาพจึงเปลี่ยนทุกครั้งที่รัน รุ่นนี้ตรึงนาฬิกาไว้แล้วที่ `previewNow()`
ใน `tools/screen-preview/Arduino.h` (เปลี่ยนได้ด้วย `PREVIEW_EPOCH`)
ผลพลอยได้คือภาพใน `docs/` ไม่ขึ้นว่าถูกแก้ทุกครั้งที่รันชุดตรวจอีกต่อไป

## กฎที่ห้ามผิดเมื่อแก้ต่อ

ไฟล์ `HostScreen.h` ถูก `#include` **ท้ายไฟล์หลัก ก่อน `setup()`** ห้ามย้ายขึ้นไปบนสุด
เพราะโค้ดในนั้นใช้ตัวแปรและฟังก์ชันช่วยที่ประกาศไว้ด้านบน

ถ้าโค้ดเหนือบรรทัด `#include` เรียกฟังก์ชันที่ย้ายไปแล้ว ต้องประกาศล่วงหน้าไว้
ในไฟล์หลัก และห้ามใส่ค่าปริยายซ้ำทั้งที่ประกาศและที่นิยาม
ตรวจด้วย `bash tools/split-check/run.sh`

---

# Central Host Gateway v4.9.2-TOUCH — พอร์ตคุณสมบัติทั้งหมดจากรุ่นจอ OLED

ต่อยอดจาก **Host จอสัมผัส 2.4" v4.9.0** โดยนำคุณสมบัติและการแก้บั๊กทั้งหมด
ที่ทำไว้ในรุ่นจอ OLED ตั้งแต่ v4.7.3 ถึง v4.7.5 มาใส่ให้ครบ
ส่วนที่รุ่นจอสัมผัสมีอยู่เดิมและรุ่น OLED ไม่มี (โมดูลนาฬิกา DS3231 และการบันทึกลง SD card)
ยังอยู่ครบทุกอย่าง ไม่ได้ตัดออก

**รุ่นเดิมยังไม่มีการแก้ไขเหล่านี้เลยแม้แต่ข้อเดียว** จึงยังมีอาการ Host ขึ้น OFFLINE
ทั้งที่เครื่องข้างเตียงทำงานปกติ ซึ่งเป็นปัญหาที่รายงานเข้ามา

## สิ่งที่พอร์ตมา

### 1. การส่ง Sync แบบไม่บล็อก (จาก v4.7.3)

ของเดิมส่งครบทุกเตียงในรอบเดียว โดยมี `delay(4)` คั่นทุกใบและ `delay(10)` เมื่อส่งไม่ผ่าน
แปดเตียงจึงทำให้ `loop()` หยุดนานได้ถึงราว **112 มิลลิวินาที** ระหว่างนั้น Host
รับข้อมูลจาก Station ไม่ได้เลย

ของใหม่แบ่งเป็น "ช่องเวลา" ส่งได้มากสุดหนึ่งใบต่อช่อง ไม่มี `delay()` ในลูปเลย
และมีคิวด่วน (`requestSyncNow`) สำหรับตอนค่าตั้งหรือรหัสเตือนเปลี่ยน

`ONLINE_TIMEOUT_MS` ขยายจาก 5 เป็น 8 วินาที ค่าเดิมสั้นเกินไปเมื่อมีหลายเตียง

### 2. การวัดคุณภาพลิงก์ (จาก v4.7.3)

วัดว่าได้รับแพ็กเก็ตจริงกี่เปอร์เซ็นต์ของที่ควรได้ใน 10 วินาทีล่าสุด
ต่างจาก RSSI ตรงที่ RSSI บอกว่าสัญญาณแรงแค่ไหน ส่วนค่านี้บอกว่าข้อมูลหายจริงหรือเปล่า
เตียงที่ RSSI ดีแต่ลิงก์ตก แปลว่าแพ็กเก็ตชนกัน ไม่ใช่สัญญาณอ่อน

### 3. ตรวจจับเลขเตียงซ้ำ (จาก v4.7.4)

เป็นสาเหตุที่พบบ่อยที่สุดของอาการ "เครื่องข้างเตียงขึ้น ONLINE แต่ Host ขึ้น OFFLINE"
Host แยกเตียงจากเลขที่เครื่องส่งมาเท่านั้น สองเครื่องที่ตั้งเลขซ้ำกันจะเขียนทับช่องเดียวกัน
จับได้จากการที่ MAC ต้นทางของเลขเตียงเดียวกันสลับไปมาถี่ผิดปกติ

พร้อมกันนี้ยังจำได้ว่าเคยได้ยินเลขเตียงใดบ้าง แม้เลขนั้นเกินจำนวนเตียงที่เปิดใช้
จึงบอกได้ว่า "ได้ยินเตียง 6 แต่ยังไม่ได้เปิดใช้"

### 4. รหัสเตือนใหม่ ALERT_NO_SIGNAL (จาก v4.7.4)

แยกกรณี "เชื่อมต่อได้และกำลังนับ แต่ไม่เคยจับหยดได้เลย" ออกจาก "สายพับ"
เพราะสายพับคือเคยไหลแล้วหยุด ส่วนอันนี้คือไม่เคยเริ่มเลย วิธีแก้คนละอย่าง

รหัสนี้ถูกแปลงเป็น `ALERT_NONE` ก่อนส่งให้ Station เสมอ เพื่อให้เข้ากันได้กับ
Station รุ่นเก่าที่ไม่รู้จักรหัสนี้

### 5. แอนิเมชันหยดน้ำเกลือ (จาก v4.7.5)

ไม่ได้เดาจังหวะเอง แต่ล็อกเฟสกับหยดจริงที่ Station วัดได้ โดยย้อนจาก `msSinceLastDrop`
รวมการแก้ของ v4.7.5 ที่เพดานคาบสั้นเกินไปจนวาด "หยดปลอม" คั่นระหว่างหยดจริงที่อัตราต่ำ

### 6. แก้บั๊ก oldPlan อ่านค่าหลังเขียนทับ (จาก v4.7.5)

รุ่นจอสัมผัสมีบั๊กเดียวกัน `oldPlan` ถูกประกาศใต้บล็อกที่เขียนค่าใหม่ไปแล้ว
จึงได้ค่าใหม่เสมอ เงื่อนไขเทียบเป็นเท็จตลอด ผลคือเปลี่ยนปริมาตรถุงอย่างเดียว
ไม่เคยล้าง `nearEndAck` ถุงใหม่จึงไม่เตือนใกล้หมดอีกเลยถ้าถุงเดิมเตือนไปแล้ว

## ส่วนแสดงผลที่เพิ่มบนจอสัมผัส

* **หน้ารายละเอียดเตียง** เพิ่มบรรทัดคุณภาพลิงก์และรหัสเครื่อง (MAC)
  ถ้าพบเลขเตียงซ้ำจะขึ้น `BED ID CLASH` เป็นสีแดง
* **หน้ารายละเอียดเตียง** เพิ่มกระเปาะหยดเคลื่อนไหวที่มุมขวาของการ์ดบน
  วาดทุกเฟรมแยกจากการแคชตัวเลข หยดจึงขยับจริง
* **แถบล่างหน้าหลัก** เพิ่มการแจ้งเลขเตียงซ้ำและเตียงที่ได้ยินแต่ยังไม่เปิดใช้
  จัดให้มาก่อนการเตือนใกล้หมด เพราะเลขเตียงซ้ำทำให้เตียงที่เหลือไม่ถูกเฝ้าเลย

## หน้าเว็บ

* เพิ่มแถวคุณภาพลิงก์และรหัสเครื่องบนการ์ดทุกเตียง
* เพิ่มคำเตือนเลขเตียงซ้ำบนการ์ด
* เพิ่มแถบวินิจฉัยที่อธิบายสาเหตุและบอกวิธีแก้ ครอบคลุมสามกรณี
  คือเลขเตียงซ้ำ เลขเตียงเกินจำนวนที่เปิดใช้ และยังไม่ได้รับข้อมูลจากบางเตียง
* เพิ่มรหัสเตือน "เซนเซอร์ยังไม่จับหยด"
* API `/api/data` ส่งค่าเพิ่ม `link` `mac` `idConflict` `heardBeyond` `linkWeakPct`
  `rxTotal` และ `syncFail` โดยยังคงส่ง `rtc` `sd` และ `sdRows` ของรุ่นนี้ไว้ตามเดิม

## ผลตรวจบนเครื่อง PC

| ชุดตรวจ | ผล |
|---|---|
| `check-ino-types` | ผ่าน 20 จาก 20 ไฟล์ |
| `touch-preview` | คอมไพล์ผ่านและเรนเดอร์ครบ 12 หน้า |
| `host-rx-test` | **ผ่าน 7 จาก 7 ข้อ** รวมการตรวจจับเลขเตียงซ้ำและเลขเกินจำนวน |
| `protocol-test` | โครงสร้างแพ็กเก็ตตรงกันทุกเฟิร์มแวร์ |
| `dashboard-preview` | หน้าเว็บแสดงลิงก์ MAC และคำเตือนครบ |

**โครงสร้างแพ็กเก็ต Protocol v3 ไม่เปลี่ยนแม้แต่ไบต์เดียว** ใช้คู่กับ Station
ทุกรุ่นตั้งแต่ 7.4.x ขึ้นไปได้ตามเดิม

## หมายเหตุเรื่องหมายเลขรุ่น

โฟลเดอร์เดิมชื่อ `V_4_9_0` แต่ `APP_VERSION` ในโค้ดเขียนว่า `4.9.1-TOUCH` ซึ่งไม่ตรงกัน
รุ่นนี้จึงข้ามไปใช้ `4.9.2` ทั้งชื่อโฟลเดอร์และในโค้ด เพื่อไม่ให้กำกวม

## ยังไม่ได้ทำ

* **ยังไม่ได้ทดสอบบนฮาร์ดแวร์จริง** ทุกอย่างตรวจด้วยเครื่องมือจำลองบนเครื่อง PC เท่านั้น
* หน้าเว็บของรุ่นนี้ยังไม่มีแถบแจ้งเตือนรวมสีแดงและสีส้มแบบรุ่น OLED
  (มีเฉพาะแถบวินิจฉัย) เพราะโครงหน้าเว็บสองรุ่นต่างกันในส่วนนั้น

---

## เอกสารเดิมจากรุ่นก่อนหน้า

ต่อยอดจาก **Host จอ TFT 2.8" v4.8.0** โดยเปลี่ยนเป็น **จอสัมผัส 2.4" แนวตั้ง 240x320**
(ST7789V หรือ ILI9341 + ทัชแบบความต้านทาน XPT2046) และทำหน้าจอให้ใช้งานด้วยการแตะ
ตรรกะการวัด การแจ้งเตือน ESP-NOW (Protocol v3) และหน้าเว็บทั้งหมดเหมือนเดิมทุกประการ
ใช้คู่กับ **Station v7.4.x / v7.5.x** ได้ทันที

**เพิ่มใน v4.9.1** — นาฬิกา **DS3231** เก็บวันที่-เวลาไว้แม้ถอดไฟ (ตั้งเวลาครั้งแรกจากสมาร์ตโฟน
ผ่านหน้าเว็บ แล้วเขียนลงชิปนาฬิกาให้เอง) และ **บันทึกข้อมูลลงการ์ด SD** ที่ช่องด้านหลังจอ
เป็นไฟล์ CSV รายวัน ดาวน์โหลดจากหน้าเว็บได้โดยไม่ต้องถอดการ์ด

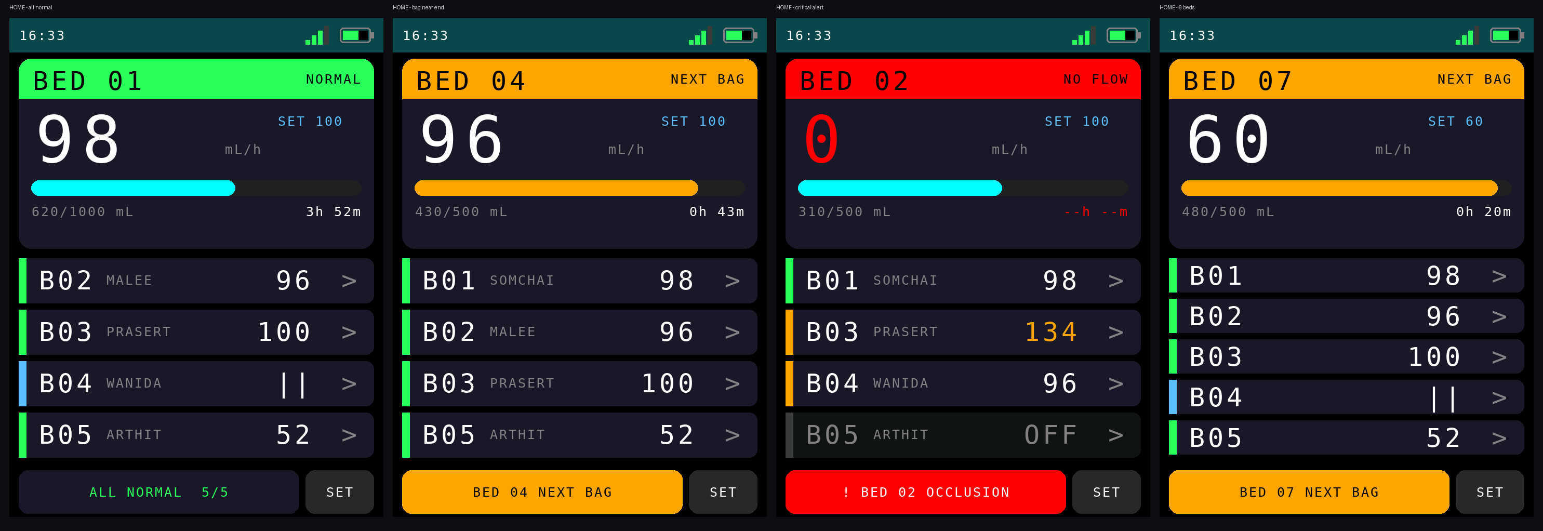
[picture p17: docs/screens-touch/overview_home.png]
หน้าหลัก


## การต่อสาย

โมดูล 2.4" มีขาสองชุด: ชุดจอ 14 ขา และชุดทัช 4-5 ขา ใช้บัส SPI ร่วมกัน

| ขาบนโมดูล | ขา ESP32-S3 | หมายเหตุ |
|---|---|---|
| VCC / GND | 3V3 / GND | |
| SCL / SCK | **GPIO 12** | `TFT_SCLK` (ทัชใช้ขานี้ร่วมกัน) |
| SDA / MOSI | **GPIO 11** | `TFT_MOSI` (ทัชใช้ขานี้ร่วมกัน) |
| RES | **GPIO 8** | `TFT_RST` |
| DC | **GPIO 9** | `TFT_DC` |
| CS | **GPIO 10** | `TFT_CS` |
| BLK | **GPIO 13** | `TFT_BLK` — ควบคุมความสว่างด้วย PWM (ตั้ง `-1` ถ้าต่อ 3V3 ตลอด) |
| T_DO (MISO) | **GPIO 16** | `TFT_MISO` — จำเป็นสำหรับอ่านค่าทัช |
| T_CS | **GPIO 14** | `TOUCH_CS_PIN` |
| T_IRQ | **GPIO 15** | `TOUCH_IRQ_PIN` (ตั้ง `255` ถ้าไม่ได้ต่อ) |
| ปุ่ม multifunction | **GPIO 4** | ต่อลงกราวด์ (ขาเดิมของปุ่ม POWER) |
| SD_CS | **GPIO 21** | `SD_CS_PIN` — ช่อง SD ด้านหลังจอ |
| SD_MOSI / SD_SCK / SD_MISO | **GPIO 11 / 12 / 16** | ต่อร่วมบัสเดียวกับจอและทัชได้เลย |
| DS3231 SDA | **GPIO 5** | `RTC_SDA_PIN` |
| DS3231 SCL | **GPIO 6** | `RTC_SCL_PIN` |

* ห้ามใช้ GPIO 33-37 บนบอร์ด N16R8 เพราะถูกใช้กับ PSRAM
* ไลบรารีที่ต้องติดตั้ง: `Adafruit GFX`, `Adafruit ST7735/ST7789`, `XPT2046_Touchscreen` (PaulStoffregen),
  `RTClib` (Adafruit) — ส่วน `SD`, `FS`, `Wire` มากับแกน ESP32 อยู่แล้ว
* โมดูล DS3231 ใส่ถ่าน CR2032 (หรือ LIR2032) ไว้ด้วย เวลาจึงจะไม่หายเมื่อดับเครื่อง
* การ์ด SD ฟอร์แมตเป็น **FAT32** (แนะนำ 4–32 GB) เสียบก่อนเปิดเครื่องหรือเสียบทีหลังก็ได้
  ระบบจะลองต่อการ์ดใหม่ให้เองทุก 30 วินาที
* ถ้าโมดูลของคุณเป็นชิป **ILI9341** ให้เปลี่ยนไปใช้ `Adafruit_ILI9341` แทน 2 บรรทัด
  (`#include` และการประกาศ `tft`) ส่วนที่เหลือใช้ได้เหมือนกัน
* ถ้าภาพกลับหัวให้เปลี่ยน `TFT_ROTATION` จาก 0 เป็น 2
* ถ้าแตะแล้วตำแหน่งสลับแกน/กลับด้าน ให้แก้ `TOUCH_SWAP_XY`, `TOUCH_FLIP_X`, `TOUCH_FLIP_Y`

## การใช้งานหน้าจอ

| หน้า | การใช้งาน |
|---|---|
| **HOME** | เตียงที่ต้องดูตอนนี้อยู่บนสุด (เลือกอัตโนมัติ: เหตุวิกฤต → ใกล้หมดถุง) ด้านล่างเป็นรายการเตียงอื่น **แตะที่ใดก็ได้เพื่อเข้าดูเตียงนั้น** มุมขวาล่างมีปุ่ม `SET` เข้าหน้าตั้งค่าระบบ |
| **BED** | รายละเอียดเตียง + ปุ่มสั่งงาน 3 ปุ่ม: `NEW BAG` (เริ่มถุงใหม่ รีเซ็ตตัวนับที่เตียง), `ACK` (รับทราบเตือนใกล้หมด), `SET` (ตั้งค่าของเตียง) |
| **BED SETTINGS** | อัตราเป้าหมาย, ปริมาตรตามแผน, Drop factor, % เตือนใกล้หมด — กด `-` `+` หรือ **แตะที่ตัวเลขเพื่อพิมพ์เอง** แล้วกด `SAVE` |
| **NUMPAD** | แป้นตัวเลขบนจอ (C = ล้าง, OK = ยืนยัน) |
| **SYSTEM** | จำนวนเตียงที่ใช้งาน, ความสว่างหน้าจอ, ปรับความแม่นจอสัมผัส, ข้อมูล Wi-Fi/เว็บ และสถานะนาฬิกา DS3231 / การ์ด SD |
| **ALARM** | ขึ้นเองเมื่อมีเหตุวิกฤต **แตะที่ไหนก็ได้ = พักเสียง 2 นาที** |

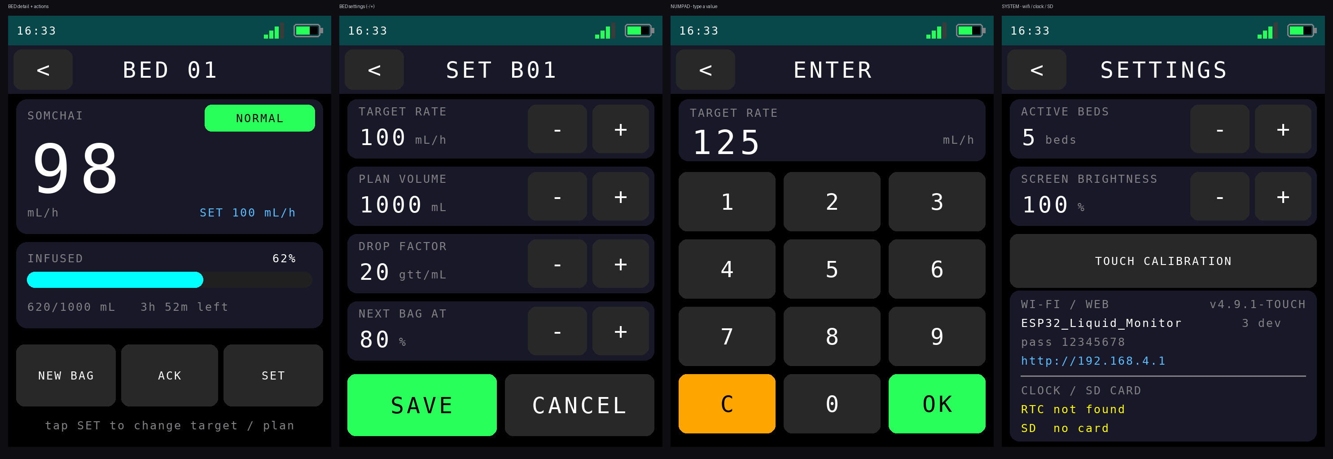
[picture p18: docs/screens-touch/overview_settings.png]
ตั้งค่าบนจอ


ค่าที่ตั้งจากหน้าจอกับที่ตั้งจากหน้าเว็บเป็นชุดเดียวกัน (บันทึกลง NVS และส่งให้เครื่องประจำเตียงทันที)

## ปุ่ม multifunction 1 ปุ่ม

| การกด | ผลลัพธ์ |
|---|---|
| คลิก 1 ครั้ง | มีเสียงเตือน = พักเสียง 2 นาที / มีเตือนใกล้หมด = รับทราบทุกเตียง / จอดับ = ปลุกจอ / อยู่หน้าย่อย = ย้อนกลับ |
| ดับเบิลคลิก | ปิด/เปิดหน้าจอ (ระบบยังทำงานและยังเตือนตามปกติ) |
| กดค้าง 2 วินาที | ปิดเครื่อง (กดค้าง 2 วินาทีอีกครั้งเพื่อเปิด) |

หน้าจอจะหรี่ลงอัตโนมัติเมื่อไม่มีการใช้งาน 3 นาที และกลับมาสว่างเมื่อแตะจอหรือกดปุ่ม
(ไม่หรี่ขณะมีเหตุเตือนหรือเตือนใกล้หมดที่ยังไม่รับทราบ)

## การปรับความแม่นของจอสัมผัส

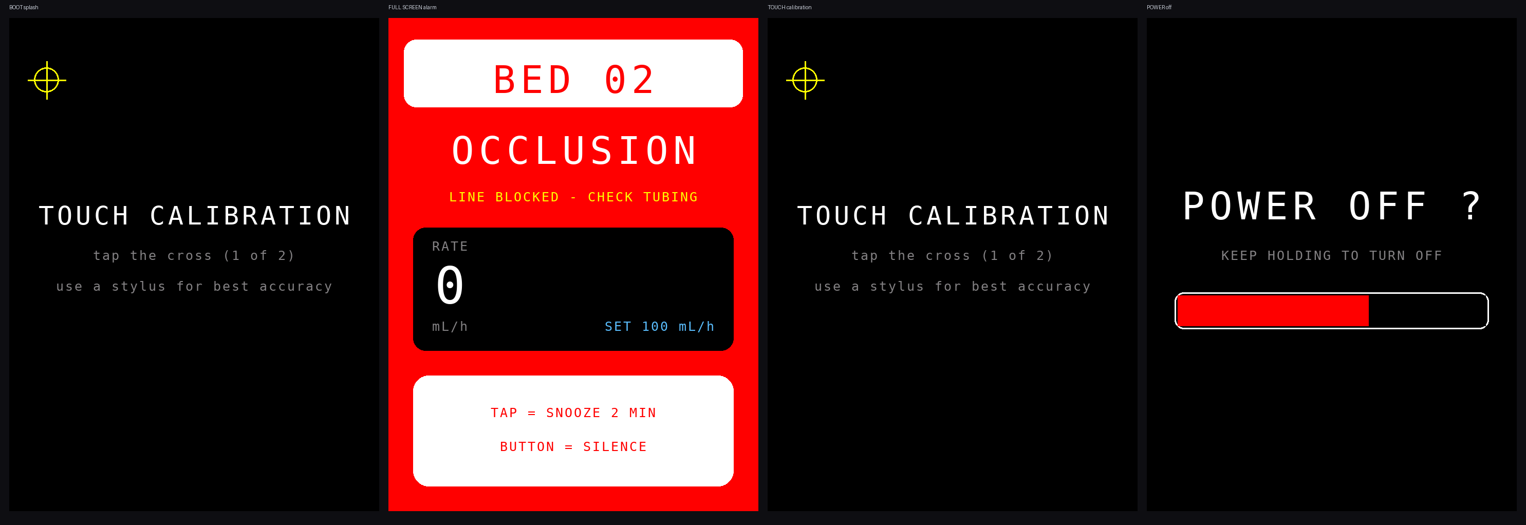
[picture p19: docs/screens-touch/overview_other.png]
หน้าจออื่น


เปิดเครื่องครั้งแรกจะเข้าหน้าปรับอัตโนมัติ — แตะกากบาท 2 จุดตามที่ปรากฏ (ใช้สไตลัสจะแม่นที่สุด)
ค่าที่ได้เก็บไว้ใน NVS และปรับใหม่ได้ทุกเมื่อจากหน้า SYSTEM

## นาฬิกา DS3231 (วันที่-เวลา)

เครื่องนี้ไม่ต่ออินเทอร์เน็ต จึงไม่มี NTP ลำดับการหาเวลาเป็นดังนี้

1. เปิดเครื่อง → อ่านเวลาจาก **DS3231** (ถ้าโมดูลมีเวลาที่ใช้ได้ ถือว่าเวลาถูกต้องทันที)
2. ถ้าไม่มีโมดูลหรือถ่านหมด → ใช้เวลาสำรองที่เก็บไว้ใน NVS (ขึ้นว่า "เวลาโดยประมาณ")
3. เปิดหน้าเว็บจากสมาร์ตโฟน/แท็บเล็ต → หน้าเว็บส่งเวลาของเครื่องนั้นให้ Host อัตโนมัติ
   (`POST /api/time/set`) แล้ว Host **เขียนเวลานั้นลง DS3231 ให้ด้วย** ตั้งครั้งเดียวก็อยู่ยาว
4. ระหว่างใช้งาน Host เทียบเวลากับ DS3231 ทุก 1 ชั่วโมง ถ้าคลาดเกิน 2 วินาทีจะปรับตาม

## การบันทึกลงการ์ด SD

ไฟล์ทั้งหมดอยู่ในโฟลเดอร์ `/IVLOG` ตั้งชื่อตามวัน (เช่น `20260916_data.csv`) ขึ้นไฟล์ใหม่ทุกวัน

| ไฟล์ | เขียนเมื่อไร | คอลัมน์ |
|---|---|---|
| `YYYYMMDD_data.csv` | ทุก 1 นาที ทุกเตียงที่ใช้งาน | `datetime, minute, bed, patient, drops, volume_ml, rate_mlhr, target_mlhr, alert, rssi, battery_v` |
| `YYYYMMDD_event.csv` | เมื่อมีเหตุการณ์ | `datetime, type, bed, detail` |

ชนิดเหตุการณ์ที่บันทึก: `BOOT`, `TIME_SET`, `NEW_BAG`, `ACK_NEAR_END`, `BED_CONFIG`,
`ALERT` (เริ่มมีเหตุเตือน) และ `ALERT_CLEAR` (กลับสู่ปกติ)

ดูและดาวน์โหลดไฟล์ได้จากหน้าเว็บ แท็บ **Log & Shift Report** → การ์ด "ไฟล์บันทึกบนการ์ด SD"
(ใช้ `GET /api/sd/list` และ `GET /api/sd/download?file=...` — เปิดเฉพาะไฟล์ในโฟลเดอร์ `/IVLOG`)
สถานะการ์ดและจำนวนแถวที่บันทึกแล้วขึ้นที่แถบสถานะด้านบนของหน้าเว็บและที่หน้า SYSTEM บนจอ

## หมายเหตุสำหรับการพัฒนาต่อ

* ทัชเป็นแบบความต้านทาน อ่านทีละจุด ไม่มี multi-touch จึงใช้เฉพาะ "แตะ" ไม่มีการปัดหรือซูม
  โค้ดอ่านค่าแบบ 1 เหตุการณ์ต่อการแตะ 1 ครั้ง พร้อมตัวกันแตะรัว 180 ms และเกณฑ์แรงกดขั้นต่ำ
* ทุกหน้าจอวาดเฉพาะส่วนที่ค่าเปลี่ยน และตอบสนองการแตะทันที (ไม่รอรอบวาดถัดไป)
* ฟอนต์มาตรฐานของ Adafruit GFX ไม่มีตัวอักษรไทย ชื่อผู้ป่วยบนจอจึงแสดงได้เฉพาะอักษรโรมัน
  (ตั้งชื่อจากหน้าเว็บได้ตามปกติ) — เวอร์ชันนี้ไม่มีแป้นพิมพ์ตัวอักษรบนจอตามที่ตกลงไว้
* ดูภาพทุกหน้าจอโดยไม่ต้องแฟลชลงบอร์ดได้ที่ `tools/touch-preview/run.sh`
* การ์ด SD ใช้บัส SPI ร่วมกับจอ จึงตั้งความเร็วไว้ 20 MHz (`SD_SPI_HZ`) ถ้าเจออาการภาพกระพริบ
  หรือเขียนไฟล์ไม่สำเร็จ ให้ลดลงเหลือ 10 MHz
* **ยังไม่ได้ทดสอบบนฮาร์ดแวร์จริง** สิ่งที่ควรตรวจก่อนใช้งาน: ทิศทางจอและทิศทางทัช,
  ความเร็ว SPI 40 MHz กับสายที่ใช้ (ลดเป็น 27 MHz ถ้าภาพรบกวน), เกณฑ์แรงกด `TOUCH_MIN_PRESSURE`,
  การอ่าน/เขียนการ์ด SD ร่วมบัสกับจอ และที่อยู่ I2C ของ DS3231 (0x68)

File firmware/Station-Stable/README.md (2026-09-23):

# เครื่องประจำเตียง สายเสถียร v7.5.5 — แยกโค้ดวาดจอออกเป็น `StationScreen.h`

ไฟล์หลักเดิมยาวจนหาของยาก รุ่นนี้ย้ายโค้ดที่ทำหน้าที่วาดจอทั้งหมดออกไปไว้ใน
ไฟล์ `StationScreen.h` ของสเก็ตช์เดียวกัน Arduino IDE แสดงเป็นแท็บคู่กัน เปิดพร้อมกันได้

```
ย้ายออกไป 556 บรรทัด    ไฟล์หลักเหลือ 2330 บรรทัด
```

**เป็นการย้ายที่อยู่ล้วน ๆ ไม่ได้แก้เนื้อในแม้แต่บรรทัดเดียว**
ตรรกะการวัด การแจ้งเตือน และโครงสร้างแพ็กเก็ต Protocol v3 เท่าเดิมทุกไบต์
ใช้คู่กับรุ่นเดิมของอีกฝั่งได้ทันที

## พิสูจน์อย่างไรว่าพฤติกรรมไม่เปลี่ยน

เรนเดอร์ภาพหน้าจอจากโค้ด **ก่อนแยก** และ **หลังแยก** แล้วเทียบทีละพิกเซล
ได้ผลว่าเหมือนกันทุกจุดครบทั้ง **18 ภาพ**

ก่อนหน้านี้เทียบแบบนี้ไม่ได้ เพราะตัวจำลองอ่านนาฬิกาจริงของเครื่อง
ภาพจึงเปลี่ยนทุกครั้งที่รัน รุ่นนี้ตรึงนาฬิกาไว้แล้วที่ `previewNow()`
ใน `tools/screen-preview/Arduino.h` (เปลี่ยนได้ด้วย `PREVIEW_EPOCH`)
ผลพลอยได้คือภาพใน `docs/` ไม่ขึ้นว่าถูกแก้ทุกครั้งที่รันชุดตรวจอีกต่อไป

## กฎที่ห้ามผิดเมื่อแก้ต่อ

ไฟล์ `StationScreen.h` ถูก `#include` **ท้ายไฟล์หลัก ก่อน `setup()`** ห้ามย้ายขึ้นไปบนสุด
เพราะโค้ดในนั้นใช้ตัวแปรและฟังก์ชันช่วยที่ประกาศไว้ด้านบน

ถ้าโค้ดเหนือบรรทัด `#include` เรียกฟังก์ชันที่ย้ายไปแล้ว ต้องประกาศล่วงหน้าไว้
ในไฟล์หลัก และห้ามใส่ค่าปริยายซ้ำทั้งที่ประกาศและที่นิยาม
ตรวจด้วย `bash tools/split-check/run.sh`

---

# Bed Station Node v7.5.4 — แก้สูตรคำนวณอัตราการไหลให้ตรงกับวิธีที่พยาบาลวัด

ต่อยอดจาก **Station v7.5.3** โดยแก้อย่างเดียวคือ **วิธีคำนวณอัตราการไหล**
การตรวจจับหยด หน้าจอ การหมุนจอ เสียงเตือน จังหวะส่ง ESP-NOW และโครงสร้าง
แพ็กเก็ต (Protocol v3) ไม่เปลี่ยนแม้แต่ไบต์เดียว ใช้คู่กับ Host รุ่นเดิมได้ทันที

## ปัญหาที่แก้ (ใหม่ใน v7.5.4)

### อาการ
ตัวเลข mL/h บนจอแกว่งแรง และเมื่อพยาบาลนับหยด 1 นาทีตามคู่มือแล้วเทียบกับจอ
มักได้ผลต่างเกินกรอบ **±10%** ที่คู่มือใช้ตัดสินการคาลิเบรต ทั้งที่เครื่องไม่ได้ผิดอะไร

### สาเหตุ — เฉลี่ย "ส่วนกลับ" ของเวลา

ของเดิมคำนวณอัตราไหลจากหยดแต่ละหยด แล้วเฉลี่ยแบบถ่วงน้ำหนัก

```cpp
instantGttMin   = 60000 / dropDeltaMs;            // อัตรา ณ ขณะนั้น
instantRateMlHr = instantGttMin * 60 / dropFactor;
currentFlowRate_ml_hr = instantRateMlHr * 0.75 + currentFlowRate_ml_hr * 0.25;
```

การเฉลี่ย `1/Δt` มีปัญหาสองข้อพร้อมกัน

1. **เอนสูงเสมอ** — ตามอสมการเจนเซน ค่าเฉลี่ยของส่วนกลับ ≥ ส่วนกลับของค่าเฉลี่ย
   ยิ่งหยดไม่สม่ำเสมอ ค่าที่อ่านได้ยิ่งสูงกว่าความจริง
2. **แกว่งแรง** — น้ำหนัก 0.75 เกาะค่าขณะนั้นเกือบเต็ม ความไม่สม่ำเสมอตามธรรมชาติ
   ของหยดจึงผ่านขึ้นจอเกือบทั้งหมด

ตัวอย่างจริง หยดสลับ 1.0 / 1.4 วินาที (เฉลี่ย 1.2 วินาที = **150 mL/h พอดี** ที่ DF 20)

```
i_a = 60000/1000 = 60.00 gtt/min      i_b = 60000/1400 = 42.86 gtt/min
x_a = 0.75·60.00 + 0.25·x_b  ->  56.57
x_b = 0.75·42.86 + 0.25·x_a  ->  46.28
จอแกว่ง 138.9 - 169.7 mL/h   (กรอบ ±10% คือ 135 - 165)
```

### วิธีแก้ — นับหยดจริงในหน้าต่างเวลา

```cpp
#define RATE_WINDOW_DROPS 8
// N ตัวอย่างเวลา = N-1 ช่วง = มีหยดตกจริง N-1 หยดในช่วงนั้น
mL/h = (N-1) / dropFactor * 3600000 / (t_ใหม่สุด - t_เก่าสุด)
```

เป็นวิธีเดียวกับที่พยาบาลนับหยด 1 นาที และเดียวกับที่ Host บันทึกลง Log รายนาที
(`entry.rateHr = minuteDrops / df * 60`) ตัวเลขทั้งสามจุดจึงตรงกันโดยนิยาม

หน้าต่างจะถูกล้างเมื่อจังหวะการไหลไม่ต่อเนื่องจริง ๆ เท่านั้น

| เหตุ | ทำไม |
|---|---|
| เริ่มถุงใหม่ / กลับจากหยุดชั่วคราว | ช่วงเวลาที่ขาดหายไม่ใช่การไหล |
| ช่วงหยด ≤ 55 ms หรือ ≥ `MAX_OCCLUSION_MS` | ช่วงผิดปกติ ไม่เอามาปน |
| ช่วงหยดต่างจากค่าเฉลี่ยในหน้าต่างเกิน 3 เท่า | พยาบาลหมุนโรลเลอร์แคลมป์ = เปลี่ยนอัตราก้าวกระโดด ทิ้งค่าเก่าทันทีไม่ให้ถ่วงจนตรวจจับช้า |
| ตรวจพบสายพับ | ค่าก่อนสายพับไม่ควรถ่วงค่าหลังแก้สายเสร็จ |

### ผลการทดสอบบนเครื่อง PC

ของจริง 150 mL/h (DF 20) วัดช่วงค่าที่อ่านได้หลังเข้าที่แล้ว

| รูปแบบการหยด | ของจริง | สูตรเดิม | สูตรใหม่ |
|---|---|---|---|
| สม่ำเสมอ 1200 ms | 150.0 | 150.0 – 150.0 ผ่าน | 150.0 – 150.0 ผ่าน |
| สลับ 1000/1400 ms | 150.0 | **138.9 – 169.7 หลุด ±10%** | 146.5 – 153.7 ผ่าน |
| สลับ 800/1600 ms | 150.0 | **135.0 – 202.5 หลุด ±10%** | 143.2 – 157.5 ผ่าน |
| ช้า 9000 ms | 20.0 | 20.0 – 20.0 ผ่าน | 20.0 – 20.0 ผ่าน |

เทียบกับสูตรที่ Host ใช้บันทึก Log: **ต่างกัน 0.000%**

---

## เอกสารเดิมจากรุ่นก่อนหน้า

ต่อยอดจาก **Station v7.5.2** โดยแก้อย่างเดียวคือ **จังหวะการส่งข้อมูลให้ Host**
ส่วนอื่นทั้งหมด (การตรวจจับหยด หน้าจอ การหมุนจอ เสียงเตือน) ไม่เปลี่ยนแม้แต่บรรทัดเดียว

ต่อยอดจาก **Station v7.5.1** โดยเพิ่มอย่างเดียวคือ **การหมุนจอ 180 องศา**
(พอร์ตมาจาก v7.7.1) ระบบคัดกรองหยดและหน้าคาลิเบรตของ v7.5.1 ไม่เปลี่ยนแม้แต่บรรทัดเดียว

ตัวสายสัญญาณต่อยอดจาก **Station v7.5.0** โดย **เปลี่ยนเฉพาะวิธีตรวจจับหยดและหน้าคาลิเบรต**
หน้าจอทั้ง 4 หน้า การสื่อสาร ESP-NOW (Protocol v3) และการแจ้งเตือนเหมือนเดิมทุกไบต์
ใช้คู่กับ **Host v4.6.0 / v4.7.0 / v4.8.0 / v4.9.x** ได้ทันที และใช้ผังขาเดิม (เซนเซอร์ที่ GPIO 4)

คำอธิบายการออกแบบหน้าจอทั้ง 4 หน้าและจอแจ้งเตือน อยู่ใน
[README ของ v7.5.0](../**Station v7.5.0**/README.md) ซึ่งยังใช้ได้ทั้งหมด

## แก้อาการ Host ขึ้น OFFLINE เมื่อมีหลายเตียง (ใหม่ใน v7.5.3)

อาการ: มีหลายเตียงพร้อมกันแล้วจอ Station ยังขึ้น `ONLINE` ปกติ แต่ฝั่ง Host
ขึ้นว่าเตียงนั้น `OFFLINE` เป็นช่วง ๆ ยิ่งเตียงมากยิ่งบ่อย

### สาเหตุจริง — ไม่ใช่สัญญาณอ่อน แต่เป็นจังหวะส่งที่ชนกันค้าง

ของเดิมทุกสเตชันส่งข้อมูลทุก **1000 ms เป๊ะ ไม่มีการสุ่มเลย**

คริสตัลของบอร์ดสองตัวต่างกันราว 40 ppm = คาบส่งเลื่อนหากันเพียง **0.04 ms ต่อวินาที**
เฟรม ESP-NOW ขนาด 23 ไบต์ใช้เวลาออกอากาศราว **0.8 ms** ดังนั้นเมื่อสองเตียงบังเอิญ
ส่งห่างกันไม่ถึง 0.8 ms มันจะชนกัน **ค้างอยู่ราว 40 วินาที** กว่าจะเลื่อนพ้นกัน

```
2 x 0.8 ms / 0.04 ms ต่อวินาที = 40 วินาที
```

40 วินาที นานกว่าเกณฑ์ `ONLINE_TIMEOUT_MS` ของ Host หลายเท่า เตียงนั้นจึงหายไปจากจอ Host

### ทำไมจอ Station ถึงยังขึ้นว่าออนไลน์

Host ส่ง Sync **แยกใบต่อเตียง** มีกี่เตียงก็ส่งเท่านั้นใบต่อวินาที และโค้ดฝั่ง Station
ตั้ง `isHostOnline = true` ทุกใบที่รับได้ ไม่ว่าจะจ่าหน้าถึงเตียงใด (ดู `OnTimeSyncRecv`)

| ทิศทาง | แพ็กเก็ต/วินาที | ต้องหายติดกันกี่ใบจึงขึ้นว่าหลุด |
|---|---|---|
| Host -> Station | เท่าจำนวนเตียง (8 เตียง = 8 ใบ) | 40 ใบ |
| Station -> Host | 1 ใบเสมอ | 5 ใบ (Host รุ่นเดิม) |

ความทนทานต่างกัน 8 เท่า จึงเห็นอาการ "ข้างหนึ่งปกติ อีกข้างหลุด"

### วิธีแก้

```cpp
#define SEND_JITTER_MS  60      // สุ่มคาบส่งในช่วง 940-1060 ms

// หลังส่งทุกครั้ง สุ่มคาบถัดไปใหม่
nextSendDelay = (SEND_INTERVAL_MS - SEND_JITTER_MS) + random(0, 2 * SEND_JITTER_MS + 1);
```

* **สุ่มคาบใหม่ทุกครั้ง** — สองเตียงที่บังเอิญชนกันจะแยกจากกันในรอบถัดไปทันที
  ไม่ใช่รอ 40 วินาที
* **รอบแรกหลังบูตเหลื่อมตามเลขเตียง** (เตียงละ 111 ms) แพ็กเก็ตกระจายกันทั้งวินาที
  ตั้งแต่ต้น ไม่ต้องรอให้ jitter ค่อย ๆ แยก
* **เมล็ดสุ่มมาจาก MAC ของบอร์ด** จึงไม่ซ้ำกันแม้แฟลชเฟิร์มแวร์เดียวกันทุกตัว

อัตราการส่งเฉลี่ยยังเท่าเดิม (1 ใบ/วินาที) โครงสร้างแพ็กเก็ตไม่เปลี่ยน
**ใช้กับ Host รุ่นใดก็ได้ และใช้ปนกับสเตชันรุ่นเก่าได้**

### วัดผลได้

```bash
tools/link-sim/run.sh
```

| จำนวนเตียง | เวลาที่ Host ขึ้น OFFLINE ผิดพลาดใน 1 ชั่วโมง (เดิม) | (ใหม่) |
|---|---|---|
| 2 | 0 วินาที | 0 วินาที |
| 4 | 203 วินาที | **0 วินาที** |
| 6 | 712 วินาที | **0 วินาที** |
| 8 | 407 วินาที | **0 วินาที** |

แนะนำให้อัปเดต Host เป็น [`v4.7.3-OLED`](../**Host จอ OLED v4.7.3**/README.md) ด้วย
ซึ่งแก้ฝั่ง Host อีกสองจุด (เลิกยิง Sync เป็นชุด และวัดคุณภาพลิงก์ให้เห็น)

## ปัญหาที่แก้ และสาเหตุจริง

### 1. อ่านเบิ้ล — เป็นบั๊กในตัวกันสัญญาณรัว ไม่ใช่เรื่องเซนเซอร์

โค้ดเดิมใน `checkAnalogDrop()` เป็นแบบนี้

```c
if (!dropState && (sensorValue < dropThreshold)) {
  if (now - lastDebounceTime > minDropInterval) {   // 55 ms
    dropState = true;  totalDrops++;  lastDebounceTime = now;
  }
}
else if (dropState && (sensorValue > dropThreshold + hysteresis)) dropState = false;
```

เมื่อค่าต่ำกว่าเกณฑ์ **แต่ยังไม่พ้น 55 ms** โปรแกรมจะไม่นับ — และก็ **ไม่ตั้ง `dropState`** ด้วย
ตัวจับจึงยัง "ง้าง" ค้างอยู่ พอครบ 55 ms ขณะที่สัญญาณยังต่ำอยู่ ก็นับซ้ำจากหยดเดิมทันที
ถ้าสัญญาณค้างต่ำอยู่ 170 ms ก็จะนับ 3 ครั้งจากหยดเดียว นี่คืออาการ "เหมือนกดสวิตช์แล้วลั่น"
ที่พบ และยิ่งเกณฑ์อยู่ใกล้ระดับปกติเท่าไร อาการยิ่งบ่อยขึ้น

**วิธีแก้:** นับตอน **"พัลส์จบ"** ที่จุดเดียวในโค้ด แล้วบังคับให้สัญญาณกลับมานิ่งใต้เกณฑ์ปลด
ต่อเนื่อง 20 ms ก่อนจึงจะรับพัลส์ถัดไปได้ โครงสร้างนี้ทำให้ **1 พัลส์ = 1 หยด เสมอ**
ไม่ว่าพัลส์จะยาวแค่ไหนหรือสัญญาณจะสั่นกี่ครั้งระหว่างทาง

### 2. หาช่วงต่างยาก — เพราะของเดิมวัดผิดสิ่ง

Wizard เดิมให้วัดค่านิ่ง 2 ค่า คือ "กระเปาะมีสารน้ำ" กับ "กระเปาะเปล่า" แล้วตั้งเกณฑ์ที่กึ่งกลาง

แต่สิ่งที่ต้องตรวจจับจริง ๆ คือ **หยดที่ตกผ่านลำแสงในเวลาราว 10 ms** ซึ่งบังลำแสงเพียงบางส่วน
สัญญาณจึงเบนจากค่าปกติแค่เศษเสี้ยวของระยะ "มีน้ำ ↔ เปล่า" เกณฑ์กึ่งกลางจึงสูงเกินไปจนจับไม่ได้
ต้องไปขยับเซนเซอร์จนสัญญาณเฉียดเกณฑ์พอดี ซึ่งก็คือจุดที่ไม่เสถียรที่สุด — จับได้บ้างไม่ได้บ้าง
และเบิ้ลตามข้อ 1

**วิธีแก้:** เลิกใช้ค่า ADC สัมบูรณ์ หันมาวัด **"ระยะเบนจากเส้นฐาน" (delta)** โดยเส้นฐาน
ไล่ตามค่าปกติเองตลอดเวลา และเกณฑ์มาจากการวัดหยดจริงในขั้นตอนคาลิเบรต

## สายสัญญาณใหม่

```
ADC 2 kHz ─► มีเดียน 5 จุด ─► เส้นฐานปรับอัตโนมัติ ─► delta
          ─► หักองค์ประกอบช้าออก ─► deltaEdge ─► ชมิตต์ทริกเกอร์ ─► ประตูรูปร่าง ─► นับ
```

`deltaEdge` คือ **สัญญาณที่ตัวตรวจจับใช้ตัดสินจริง** และเป็นค่าเดียวกับที่วาดบนกราฟ
ในหน้าคาลิเบรตและที่แสดงบนหน้า 3 LINK — ถ้ากราฟทะลุเส้นเกณฑ์ ตัวตรวจจับก็เห็นเหมือนกัน

| ส่วน | ทำอะไร | แก้ปัญหาอะไร |
|---|---|---|
| อ่านที่คาบคงที่ 2 kHz | พัลส์กว้าง 10 ms ได้ตัวอย่างราว 20 จุด | เดิมอ่านรอบละครั้งตามจังหวะ loop ซึ่งไม่สม่ำเสมอ |
| มีเดียน 5 จุด | ตัดสไปก์เดี่ยว | ADC ของ ESP32 กระโดดแรงตอน Wi-Fi/ESP-NOW ส่งข้อมูล |
| เส้นฐานปรับอัตโนมัติ (~0.5 วินาที) | ตามการดริฟต์ของอุณหภูมิ แสงรอบข้าง แรงดันไฟ | ไม่ต้องคาลิเบรตใหม่เมื่อสภาพแวดล้อมเปลี่ยน |
| หยุดเส้นฐานระหว่างมีพัลส์ | เส้นฐานไม่ไล่ตามหยดจนกลืนหายไป | หยดยาวไม่ถูกมองข้าม |
| ชมิตต์ทริกเกอร์ (เข้า/ออกคนละระดับ) | เกณฑ์ปลด = 40% ของเกณฑ์เข้า | สัญญาณสั่นรอบเกณฑ์ไม่ทำให้นับซ้ำ |
| กรองความกว้าง 2-150 ms | แคบไป = สัญญาณรบกวน, กว้างไป = ไม่ใช่หยด | กันทั้งสไปก์และการที่ระดับน้ำ/สิ่งบังลำแสงเปลี่ยน |
| นับตอนพัลส์จบ + รอนิ่ง 20 ms | 1 พัลส์ = 1 หยด | **แก้อาการอ่านเบิ้ลโดยตรง** |
| กู้เส้นฐานอัตโนมัติเมื่อค้างเกิน 300 ms | ระดับสัญญาณที่เลื่อนไปค้างจะถูกยึดเป็นเส้นฐานใหม่ | กันเครื่องค้างจนไม่นับหยดอีกเลย |
| **หักองค์ประกอบช้าออก (30 ms / 10 ms ตอนแกว่ง)** | เหลือเฉพาะยอดแหลมของหยด | **กันถุงน้ำเกลือแกว่งตอนคนไข้เดิน** |
| **แทรกการอ่านเซนเซอร์ระหว่างวาดกราฟ** | การวาดจอไม่ทำให้การอ่านขาดช่วง | **แก้อาการกราฟขึ้นแท่งเหลืองแต่ไม่นับ** |
| **เรียนรู้รูปร่างหยดต่อเนื่อง** | จำความสูง/ความกว้างหยด แล้วปรับเกณฑ์ตามเอง | ตามการเปลี่ยนแปลงช้า ๆ ได้โดยไม่ต้องคาลิเบรตใหม่ |
| รู้ทิศสัญญาณเอง | หยดทำให้ค่าลดลงหรือเพิ่มขึ้นก็ได้ | ติดตั้งเซนเซอร์กลับด้านก็ยังใช้ได้ |
| ตั้งต้นใหม่เมื่ออ่านขาดช่วง > 25 ms | ไม่เดาพัลส์ที่มองเห็นไม่ครบ | ตอนวาดจอทั้งหน้าจะไม่เกิดหยดผี |

## หน้าคาลิเบรตใหม่ (กดปุ่มค้าง 3 วินาที)

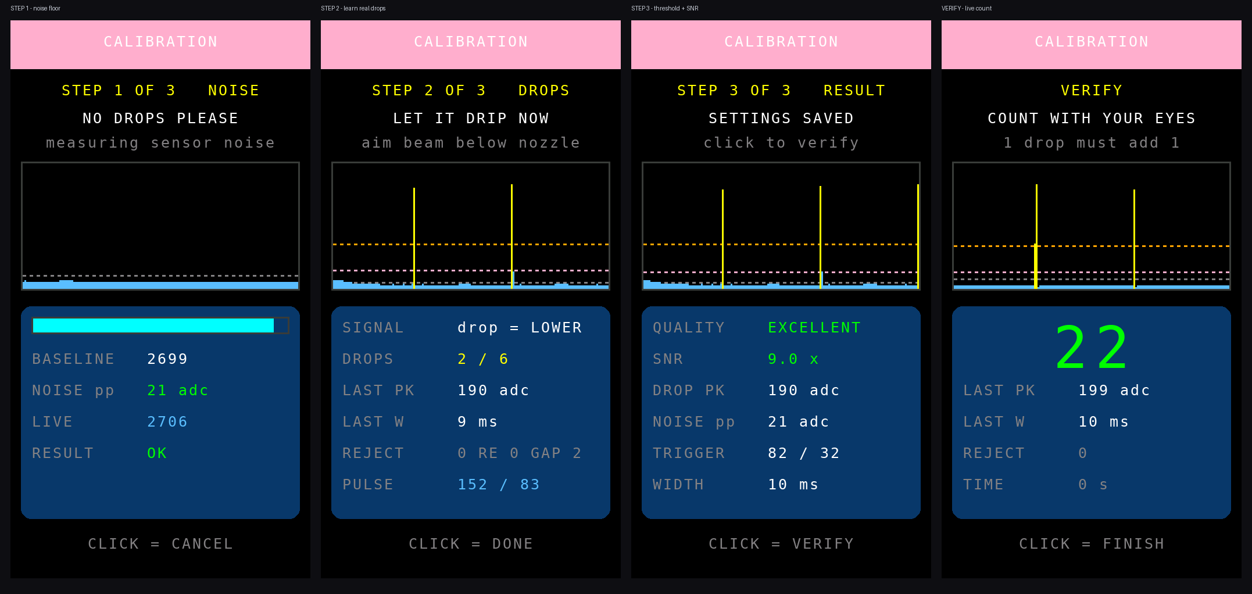
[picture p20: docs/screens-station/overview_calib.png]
หน้าคาลิเบรต


ทุกหน้ามี **จอคลื่นสด** อยู่ด้านบน แสดง delta ย้อนหลังราว 2.5 วินาที
เส้นประส้ม = เกณฑ์เข้า, เส้นประชมพู = เกณฑ์ปลด, เส้นประเทา = ระดับสัญญาณรบกวน
แท่งสีฟ้า = ช่วงว่าง, แท่งสีเหลือง = ช่วงที่เกินเกณฑ์ (คือหยด) — **เห็นด้วยตาทันทีว่าอันไหนคืออะไร**

### ขั้นที่ 1 — NOISE (3 วินาที, ห้ามมีหยด)

วัด **พื้นสัญญาณรบกวน** ของเซนเซอร์ตัวนี้ในตำแหน่งติดตั้งจริง นี่คือขีดล่างของฮาร์ดแวร์:
สัญญาณของหยดที่เล็กกว่านี้ ไม่มีอัลกอริทึมใดแยกออกได้

| NOISE pp | หมายความว่า |
|---|---|
| ≤ 20 | VERY QUIET — ดีมาก |
| 21-60 | OK — ใช้งานได้สบาย |
| 61-150 | NOISY — ควรหาทางลดก่อน (ดูหัวข้อฮาร์ดแวร์ด้านล่าง) |
| > 150 | VERY NOISY — ต้องแก้ก่อน ไม่งั้นจะนับพลาดแน่ |

### ขั้นที่ 2 — DROPS (ให้น้ำหยดจริง 6 หยด หรือเร็วกว่านั้น)

จบให้อัตโนมัติทันทีที่ได้ **3 หยดที่ความสูงใกล้เคียงกัน (ต่างกันไม่เกิน 40%)**
เพราะแค่นั้นก็รู้จักหยดแล้ว ถ้าความสูงยังกระโดดไปมาจะเก็บต่อจนครบ 6 หยด
โดยทั่วไปใช้เวลาราว 3-6 วินาที (เดิมต้องรอครบ 10 หยด)

ใช้เกณฑ์ไวชั่วคราว (4 เท่าของสัญญาณรบกวน) จับพัลส์จริง แล้วเก็บ **ความสูง** และ **ความกว้าง**
ของแต่ละหยด พร้อมเดาทิศสัญญาณให้เอง

แถวล่างสุดบอก **สถานะของตัวตรวจจับ** ซึ่งช่วยวินิจฉัยได้ทันทีเวลาตัวเลขไม่ขึ้น

| สถานะ | ความหมาย |
|---|---|
| `WATCH` | กำลังเฝ้ารอพัลส์ถัดไป (สถานะปกติระหว่างหยด) |
| `PULSE` | พัลส์กำลังดำเนินอยู่ |
| `SETTLE` | พัลส์จบแล้ว กำลังรอให้สัญญาณนิ่งก่อนรับหยดถัดไป |

ถ้าค้างที่ `SETTLE` ตลอดแปลว่าสัญญาณไม่เคยกลับลงมาใต้เกณฑ์ปลดเลย และช่อง `RE`
(จำนวนครั้งที่ต้องยึดเส้นฐานใหม่) จะเดินขึ้น — ดูหัวข้อ "แก้ปัญหาที่พบบ่อย" ด้านล่าง

### ขั้นที่ 3 — RESULT (คำนวณและบันทึก)

ตั้งเกณฑ์ที่ **จุดกึ่งกลางระหว่างสองข้อจำกัด**

```
ขอบล่าง = 3 × สัญญาณรบกวนยอดถึงยอด      (ต้องพ้นสัญญาณรบกวนให้ขาด)
ขอบบน   = 55% ของหยดที่จางที่สุด          (ต้องต่ำพอที่หยดจางสุดยังผ่าน)
เกณฑ์เข้า = (ขอบล่าง + ขอบบน) / 2
เกณฑ์ปลด = 40% ของเกณฑ์เข้า
```

แล้วรายงาน **SNR = ความสูงหยดกลาง ÷ สัญญาณรบกวน** ซึ่งเป็นตัวเลขที่บอกตรง ๆ ว่า
ตำแหน่งติดตั้งนี้ดีพอหรือยัง

| SNR | คำตัดสิน | ควรทำอะไร |
|---|---|---|
| ≥ 8.0 | EXCELLENT | ใช้ได้เลย |
| 5.0-7.9 | GOOD | ใช้ได้ |
| 3.0-4.9 | FAIR | พอใช้ แต่ถ้าขยับเซนเซอร์ได้จะดีกว่านี้ |
| 2.0-2.9 | POOR | จะมีพลาดบ้าง ควรแก้ตำแหน่ง |
| < 2.0 | TOO WEAK | ยังไม่ควรใช้ ต้องแก้ฮาร์ดแวร์ก่อน |

ถ้าความสูงของหยดแต่ละหยดต่างกันเกิน 80% จะขึ้นเตือน `UNEVEN - ALIGN SENSOR`
แปลว่าหยดบางหยดผ่านขอบลำแสงแทนที่จะผ่านกลางลำแสง

### ขั้นตรวจสอบ — VERIFY (20 วินาที)

นับหยดสดด้วยค่าที่เพิ่งได้ ให้นับด้วยตาเทียบกับตัวเลขบนจอ **หยด 1 หยดต้องขึ้น 1 พอดี**
ถ้าขึ้นทีละ 2 แสดงว่ายังมีอะไรผิด (ดูช่อง REJECT และรูปคลื่นประกอบ)

กดปุ่มระหว่างขั้นที่ 1 หรือ 2 = ยกเลิก **โดยไม่เขียนทับค่าเดิมที่ใช้งานได้อยู่**

## ดูค่าสดได้จากหน้า 3 LINK

การ์ด SENSOR เปลี่ยนจาก `ADC / TH / HYS` มาแสดง

* `D <ตัวเลข>` — ระยะเบนจากเส้นฐานตอนนี้ ปกติจะแกว่งใกล้ 0 และพุ่งขึ้นตอนมีหยด
  (ตัวเลขเปลี่ยนเป็นสีเหลืองขณะที่พัลส์กำลังดำเนินอยู่)
* `TRIG / NOISE` — เกณฑ์ที่ใช้อยู่ และสัญญาณรบกวนที่วัดได้สด ๆ
* `SNR x.x <คำตัดสิน>` หรือ `NOT CALIBRATED`

## ทำให้เซนเซอร์อินฟราเรดดีที่สุดเท่าที่ทำได้

อัลกอริทึมช่วยได้ถึงขีดหนึ่ง ที่เหลือเป็นเรื่องฮาร์ดแวร์ เรียงตามผลที่ได้จริง

1. **ตำแหน่งลำแสง** — เล็งให้ลำแสงตัดผ่านทางที่หยดตก **ต่ำกว่าปลายหัวหยดราว 3-5 มม.**
   ตรงนั้นหยดยังเป็นก้อนกลมและเคลื่อนที่เร็ว สัญญาณจึงคมและสูง
   ถ้าเล็งต่ำเกินไปหยดจะยืดตัวและอาจแตก ทำให้ได้พัลส์เตี้ยและอาจมี 2 ลูกติดกัน
   **อย่าเล็งไปที่ผิวน้ำด้านล่างของกระเปาะ** เพราะระดับน้ำเปลี่ยนช้า ๆ ไม่ใช่พัลส์
2. **ให้ลำแสงผ่านกลางทางหยด** ไม่ใช่ขอบ — ถ้าความสูงพัลส์แต่ละหยดต่างกันมาก (ขึ้น
   `UNEVEN`) แปลว่ายังไม่ตรงกลาง
3. **บังแสงรอบข้าง** — แสงแดดและหลอด LED บางรุ่นมีอินฟราเรดปนมาก ครอบกระเปาะด้วยปลอกทึบ
   จะลด NOISE pp ได้มากที่สุดในบรรดาวิธีทั้งหมด
4. **กรองไฟเลี้ยงเซนเซอร์** — ใส่ 100 nF ขนานกับ 10 µF ที่ขา VCC-GND ของโมดูล ให้ชิดตัวโมดูล
   ADC ของ ESP32 จะกระโดดตามจังหวะที่ Wi-Fi ส่งข้อมูล การกรองไฟช่วยได้ชัดเจน
5. **กรองสาย AO** — ใส่ตัวเก็บประจุ 1-10 nF จากขา AO ลงกราวด์ที่ฝั่ง ESP32
   ช่วยกัดความถี่สูงออกก่อนเข้า ADC (มีเดียน 5 จุดในเฟิร์มแวร์ช่วยอีกชั้น)
6. **สายสั้นและบิดเกลียว** — สาย AO ที่ยาวและเดินคู่กับสายจอ SPI จะรับสัญญาณรบกวนเข้ามา
7. **ความสะอาดของกระเปาะ** — คราบและฟองเกาะผนังทำให้ความสูงพัลส์ไม่สม่ำเสมอ

ทำข้อ 1-3 ก่อนเสมอ แล้วกดคาลิเบรตใหม่ดู SNR ว่าขยับขึ้นไหม — หน้าคาลิเบรตออกแบบมา
ให้ใช้เป็นเครื่องมือวัดตอนจัดตำแหน่งได้โดยตรง

## เครื่องเรียนรู้หยดอย่างไร

หลังคาลิเบรตเสร็จ เครื่องจะจำ **ความสูง** และ **ความกว้าง** ของหยดไว้ แล้ว
**เรียนรู้ต่อไปเรื่อย ๆ จากหยดจริงทุกหยด** (ค่าเฉลี่ยแบบถ่วงน้ำหนัก 1/8 ต่อหยด)
พร้อมปรับเกณฑ์เข้าให้เท่ากับ 45% ของความสูงที่เรียนรู้ไว้ แต่ไม่ต่ำกว่า 3 เท่าของสัญญาณรบกวน

ดูค่าที่เรียนรู้ได้ที่หน้า **3 LINK** บรรทัดล่างสุด (`LEARNED <ความสูง> / <ความกว้าง>ms`)
และค่าที่ได้จะถูกบันทึกลง NVS ทุกครั้งที่คาลิเบรต จึงไม่หายเมื่อปิดเครื่อง

ประโยชน์: ฝุ่นเกาะกระเปาะ ไฟ LED อ่อนลงตามอายุ หรือท่าทางของสายเปลี่ยนไปเล็กน้อย
เครื่องจะขยับเกณฑ์ตามเองโดยไม่ต้องคาลิเบรตใหม่

### ถุงน้ำเกลือแกว่งตอนคนไข้เดิน

ถุงที่แกว่งทำให้สัญญาณส่ายเป็นจังหวะช้า ๆ (ราว 1-3 ครั้งต่อวินาที) ด้วยแอมพลิจูดที่อาจ
**สูงกว่าหยดจริงหลายเท่า** ถ้าตัดสินจากระดับสัญญาณอย่างเดียวจะนับการแกว่งเป็นหยดไปด้วย

วิธีแก้คือแยกตาม **ความเร็วของการเปลี่ยนแปลง** ไม่ใช่ขนาด: หยดใช้เวลาราว 10 ms
ส่วนการแกว่งใช้เวลาหลายร้อยมิลลิวินาที เครื่องจึงมีตัวตามที่ค่าคงที่เวลา 30 ms
(ลดเหลือ 10 ms อัตโนมัติเมื่อตรวจพบว่ากำลังแกว่ง) คอยไล่ตามส่วนที่เปลี่ยนช้าแล้วหักออก
เหลือเฉพาะยอดแหลมของหยดให้ตัวตรวจจับทำงาน

เมื่อตรวจพบการแกว่งจะขึ้น `MOVING - bag swinging` ที่หน้า 3 LINK และ `MOVE` ในหน้าคาลิเบรต

ผลทดสอบด้วยสัญญาณจำลอง (หยดจริง 23 หยดใน 20 วินาที)

| สภาวะ | ก่อนแก้ | หลังแก้ |
|---|---|---|
| นิ่งปกติ | 22/23 | 22/23 |
| ถุงแกว่ง 2 Hz ±150 ADC | 23/23 (คัดทิ้ง 22 ครั้ง) | 22/23 (คัดทิ้ง 0) |
| ถุงแกว่ง 1 Hz ±300 ADC | **3/23** | **22/23** |
| ระดับสัญญาณไหล 20 ADC/วินาที | 22/23 | 22/23 |
| หยดที่มีสัญญาณ 3 ยอดติดกัน | 22/23 (ไม่เบิ้ล) | 22/23 (ไม่เบิ้ล) |

## แก้ปัญหาที่พบบ่อย

### กราฟขึ้นแท่งเหลืองตามจังหวะหยดแล้ว แต่ตัวเลขไม่นับ

แท่งเหลืองบอกว่า **สัญญาณเกินเกณฑ์แล้ว** แต่การนับต้องครบวงจร คือ
เกินเกณฑ์เข้า → กลับลงมาใต้เกณฑ์ปลด → นิ่งครบ 20 ms → จึงพร้อมรับหยดถัดไป
ถ้าสัญญาณไม่เคยกลับลงมาใต้เกณฑ์ปลด ตัวตรวจจับจะค้างที่ `SETTLE` และ **ไม่นับหยดใด ๆ อีกเลย**
ทั้งที่กราฟยังขึ้นแท่งเหลืองอยู่

เกิดได้จาก: เส้นฐานตอนเริ่มเพี้ยน, เซนเซอร์ขยับ, ไฟเลี้ยงตก, แสงรอบข้างเปลี่ยน
หรือเซนเซอร์บางรุ่นที่สัญญาณคืนตัวช้าจนพัลส์กว้างกว่าที่กำหนดไว้

**สาเหตุหลักที่เจอจริงหน้างาน: การวาดกราฟกินเวลานานกว่าที่ยอมให้การอ่านขาดช่วง**
การวาดแถบกราฟทั้งแถบบนจอจริงใช้เวลาหลายสิบมิลลิวินาที ซึ่งเกิน `SENSOR_GAP_RESYNC_MS`
(25 ms) โค้ดจึงถือว่า "อ่านขาดช่วง" แล้วตั้งต้นสายสัญญาณใหม่ **ทุกครั้งที่วาดกราฟ**
ตัวตรวจจับเลยถูกดีดกลับไปเฟส `SETTLE` ตลอด จนแทบไม่เหลือจังหวะเฝ้ารอหยดเลย
ขณะที่กราฟยังวาดแท่งเหลืองตามปกติเพราะวาดจากค่าสัญญาณโดยตรง

**แก้แล้ว** ด้วย 3 อย่างพร้อมกัน

1. **แทรกการอ่านเซนเซอร์ไว้ระหว่างวาดกราฟ** (ทุก 12 คอลัมน์) การวาดจอจึงไม่ทำให้ขาดช่วงอีก
2. **การขาดช่วงไม่ล้างเส้นฐานทิ้งแล้ว** — เก็บเส้นฐานที่สะสมมาไว้ ทิ้งเฉพาะพัลส์ที่มองเห็นไม่ครบ
3. เส้นฐานไล่ตามการดริฟต์ทั้งในเฟส `WATCH` และ `SETTLE` (หยุดเฉพาะตอน `PULSE`)
   และถ้าค้างที่ `SETTLE` เกิน 300 ms จะยึดระดับปัจจุบันเป็นเส้นฐานใหม่ นับไว้ในช่อง `RE`

ช่อง `GAP` ในขั้นที่ 2 บอกจำนวนครั้งที่การอ่านขาดช่วง ปกติควรอยู่ที่ 0-2 ถ้าเดินขึ้นเรื่อย ๆ
แปลว่ามีอะไรกินเวลาในลูปหลักนานผิดปกติ

ถ้า `RE` เดินขึ้นเรื่อย ๆ แปลว่าสัญญาณยังไม่นิ่งจริง ให้ตรวจตามลำดับ

1. เซนเซอร์ขยับหรือสายหลวมไหม
2. ไฟเลี้ยงนิ่งพอไหม (ใส่ 100 nF + 10 µF ที่โมดูล)
3. แสงรอบข้างเปลี่ยนไปมาไหม (มีคนเดินผ่าน/ม่านโดนลม)
4. ถ้าเซนเซอร์คืนตัวช้ามาก ลองเพิ่ม `DROP_MAX_WIDTH_MS` จาก 250 เป็น 400

### นับได้ไม่ครบ 10 หยดในขั้นที่ 2 (ช่อง REJECT เดินขึ้น)

`REJECT` นับพัลส์ที่แคบกว่า `DROP_MIN_WIDTH_MS` (สัญญาณรบกวน) หรือกว้างกว่า
`DROP_MAX_WIDTH_MS` (ไม่ใช่หยด) ถ้าเดินขึ้นเยอะให้ดูความกว้างพัลส์จริงในช่อง `LAST W`
แล้วปรับสองค่านั้นให้ครอบคลุม

## ค่าที่ปรับได้ตอนต้นไฟล์

| `#define` | ค่าเริ่มต้น | ปรับเมื่อ |
|---|---|---|
| `SENSOR_SAMPLE_US` | 500 | อยากอ่านถี่/ห่างกว่านี้ (500 = 2 kHz) |
| `SENSOR_MEDIAN_N` | 5 | สัญญาณรบกวนเป็นสไปก์แหลมมาก ลองเพิ่มเป็น 7 |
| `BASELINE_STEP_DIV` | 1024 | เส้นฐานไล่ตามเร็ว/ช้าไป (มาก = ช้า) |
| `DROP_MIN_WIDTH_MS` | 2 | ยังมีสไปก์เล็ดลอด ลองเพิ่มเป็น 3-4 |
| `DROP_MAX_WIDTH_MS` | 250 | เซนเซอร์คืนตัวช้าจนพัลส์กว้างกว่านี้ |
| `DROP_REARM_MS` | 20 | ยังเบิ้ลอยู่ (แทบไม่ควรต้องปรับแล้ว) เพิ่มเป็น 30-40 |
| `DROP_REARM_TIMEOUT_MS` | 300 | เวลาที่ยอมให้ค้างที่ `SETTLE` ก่อนยึดเส้นฐานใหม่ |
| `DELTA_SLOW_TAU` | 300 (=30 ms) | ตัวตัดองค์ประกอบช้า — ลดลงถ้าถุงแกว่งแล้วยังนับเกิน |
| `DELTA_SLOW_TAU_MOTION` | 100 (=10 ms) | ค่าเดียวกันตอนตรวจพบว่ากำลังแกว่ง |
| `LEARN_DIV` | 8 | ความเร็วที่ค่าที่เรียนรู้ไล่ตามหยดใหม่ (มาก = ช้า) |
| `LEARN_MIN_AMP_PCT` | 35 | พัลส์ที่เตี้ยกว่านี้ (% ของที่เรียนรู้) ถือว่าไม่ใช่หยด |
| `CAL_QUICK_DROPS` | 3 | จบขั้นที่ 2 เร็วเมื่อได้หยดสม่ำเสมอเท่านี้ |

`minDropInterval` (55 ms) ยังทำหน้าที่เดิมคือกรองช่วงห่างที่สั้นเกินจริงออกจากการคำนวณอัตราไหล

## หมุนจอ 180 องศา (ใหม่ใน v7.5.2)

ตอนติดตั้งจริง ทิศที่สายเซนเซอร์และสาย USB ออกจากกล่องเป็นตัวกำหนดว่ากล่องต้องวางท่าไหน
บางตำแหน่งวางแล้วจอกลับหัว เวอร์ชันนี้จึงสลับทิศจอได้ที่หน้าเครื่องโดยไม่ต้องแฟลชใหม่

**วิธีสลับ**

1. คลิกปุ่ม **3 ครั้ง** = เข้าหน้า `SET BED ID`
2. ในหน้านี้ **ดับเบิลคลิก** = สลับ `SCREEN: NORMAL` <-> `SCREEN: FLIP 180`
   จอพลิกให้เห็นผลทันที และบันทึกลง NVS ทันทีเช่นกัน
3. คลิกเดี่ยวยังเป็นการเปลี่ยนเลขเตียง 1-8 เหมือนเดิม ไม่กระทบของเดิม

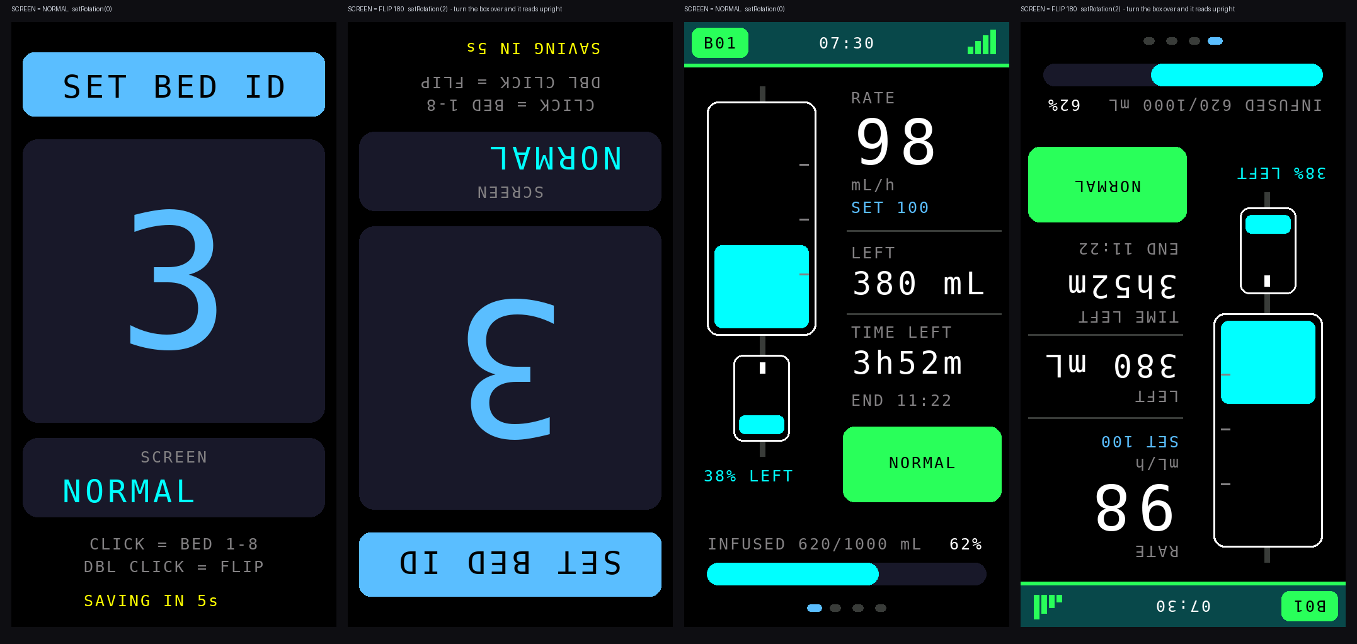
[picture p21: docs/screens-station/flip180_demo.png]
เปรียบเทียบทิศจอ


ภาพคู่ขวาของแต่ละชุดคือสิ่งที่ออกจากจอเมื่อตั้ง `FLIP 180` — เมื่อพลิกกล่องกลับ
180 องศาตามการติดตั้งจริง จะอ่านได้ตรงตามปกติ (ภาพจาก v7.7.1 หน้าจอชุดเดียวกัน)

**ตั้งค่าเริ่มต้นตอนคอมไพล์** ถ้าทั้งวอร์ดติดตั้งกลับหัวเหมือนกันหมด แก้บรรทัดเดียว
แล้วแฟลชทีเดียวจบ (ค่าที่เคยตั้งที่หน้าเครื่องจะมีลำดับสูงกว่าเสมอ)

```cpp
#define TFT_ROTATION_DEFAULT  TFT_ROT_FLIP180   // เดิมเป็น TFT_ROT_NORMAL
```

**ทำไมเลย์เอาต์ไม่ต้องแก้แม้แต่บรรทัดเดียว**

จอ ST7789 ขนาด 172x320 ที่ `setRotation(0)` กับ `setRotation(2)` เป็น **แนวตั้ง
ขนาดเท่ากันทั้งคู่** ต่างกันแค่บิต `MX`/`MY` ในรีจิสเตอร์ `MADCTL` ของตัวคอนโทรลเลอร์
คือตัวชิปเป็นผู้กลับลำดับการสแกนแถวและคอลัมน์ให้เอง พิกัด `(x, y)` ทุกจุดที่โค้ดวาด
จึงมีความหมายเหมือนเดิมทั้งหมด (ถ้าเป็น `setRotation(1)` หรือ `(3)` จะกลายเป็นแนวนอน
320x172 ซึ่งต้องรื้อเลย์เอาต์ใหม่ทั้งไฟล์ — จึงไม่ใช้)

อีกจุดที่ต้องระวังคือ **ออฟเซ็ตคอลัมน์** เพราะคอนโทรลเลอร์ ST7789 กว้าง 240 พิกเซล
แต่หน้าจอจริงกว้าง 172 พิกเซล ภาพจึงต้องเลื่อนเข้ามา `(240-172)/2 = 34` พิกเซล
ไลบรารี Adafruit ตั้ง `_colstart = _colstart2 = 34` ให้แล้วเมื่อเรียก `init(172, 320)`
ทั้งสองทิศจึงใช้ออฟเซ็ตเท่ากัน ภาพไม่เลื่อนออกนอกจอ

**ไม่กระทบสิ่งอื่นเลย** — การตรวจจับหยด หน้าคาลิเบรต 3 ขั้น การสื่อสาร ESP-NOW
เสียงเตือน และค่าที่คาลิเบรตไว้ ไม่เกี่ยวข้องกับทิศจอแม้แต่จุดเดียว
ค่าที่เคยคาลิเบรตไว้ใน NVS (`st_cal`) ยังใช้ได้ต่อ ไม่ต้องคาลิเบรตใหม่หลังอัปเกรด

## หมายเหตุ

* ค่าคาลิเบรตเก็บใน NVS namespace `st_cal` ด้วยคีย์ชุดใหม่ (`pol`, `trig`, `rel`, `amp`,
  `noise`, `snr`, `q`) — ของเดิม (`th`, `hys`, `v_liq`, `v_air`) ไม่ถูกใช้แล้วแต่ไม่ได้ลบทิ้ง
  ถ้าย้อนกลับไป v7.5.0 ค่าเดิมยังอยู่ครบ
* เครื่องที่ยังไม่เคยคาลิเบรตจะใช้ค่าเริ่มต้น (เกณฑ์ 120) และหน้า 3 จะขึ้น `NOT CALIBRATED`
* **ยังไม่ได้ทดสอบบนฮาร์ดแวร์จริง** — สิ่งที่ควรดูก่อนใช้งาน: ตัวเลข NOISE pp ในขั้นที่ 1
  สมเหตุสมผลไหม, ขั้นที่ 2 จับครบ 10 หยดโดย REJECT = 0 หรือไม่, และขั้น VERIFY นับตรงกับตาไหม
* ดูหน้าจอทุกหน้าโดยไม่ต้องแฟลชลงบอร์ดได้ที่ `tools/station-preview/run.sh`
  (ตัวเรนเดอร์มีเซนเซอร์จำลองในตัว จึงเดินหน้าคาลิเบรตได้จริงทั้ง 4 หน้า)

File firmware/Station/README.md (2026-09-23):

# เครื่องประจำเตียง สายหลัก v7.8.0 — แยกโค้ดวาดจอออกเป็น `StationScreen.h`

ไฟล์หลักเดิมยาวจนหาของยาก รุ่นนี้ย้ายโค้ดที่ทำหน้าที่วาดจอทั้งหมดออกไปไว้ใน
ไฟล์ `StationScreen.h` ของสเก็ตช์เดียวกัน Arduino IDE แสดงเป็นแท็บคู่กัน เปิดพร้อมกันได้

```
ย้ายออกไป 555 บรรทัด    ไฟล์หลักเหลือ 1695 บรรทัด
```

**เป็นการย้ายที่อยู่ล้วน ๆ ไม่ได้แก้เนื้อในแม้แต่บรรทัดเดียว**
ตรรกะการวัด การแจ้งเตือน และโครงสร้างแพ็กเก็ต Protocol v3 เท่าเดิมทุกไบต์
ใช้คู่กับรุ่นเดิมของอีกฝั่งได้ทันที

## พิสูจน์อย่างไรว่าพฤติกรรมไม่เปลี่ยน

เรนเดอร์ภาพหน้าจอจากโค้ด **ก่อนแยก** และ **หลังแยก** แล้วเทียบทีละพิกเซล
ได้ผลว่าเหมือนกันทุกจุดครบทั้ง **18 ภาพ**

ก่อนหน้านี้เทียบแบบนี้ไม่ได้ เพราะตัวจำลองอ่านนาฬิกาจริงของเครื่อง
ภาพจึงเปลี่ยนทุกครั้งที่รัน รุ่นนี้ตรึงนาฬิกาไว้แล้วที่ `previewNow()`
ใน `tools/screen-preview/Arduino.h` (เปลี่ยนได้ด้วย `PREVIEW_EPOCH`)
ผลพลอยได้คือภาพใน `docs/` ไม่ขึ้นว่าถูกแก้ทุกครั้งที่รันชุดตรวจอีกต่อไป

## กฎที่ห้ามผิดเมื่อแก้ต่อ

ไฟล์ `StationScreen.h` ถูก `#include` **ท้ายไฟล์หลัก ก่อน `setup()`** ห้ามย้ายขึ้นไปบนสุด
เพราะโค้ดในนั้นใช้ตัวแปรและฟังก์ชันช่วยที่ประกาศไว้ด้านบน

ถ้าโค้ดเหนือบรรทัด `#include` เรียกฟังก์ชันที่ย้ายไปแล้ว ต้องประกาศล่วงหน้าไว้
ในไฟล์หลัก และห้ามใส่ค่าปริยายซ้ำทั้งที่ประกาศและที่นิยาม
ตรวจด้วย `bash tools/split-check/run.sh`

---

# Bed Station Node v7.7.3 — แก้สูตรคำนวณอัตราการไหลให้ตรงกับวิธีที่พยาบาลวัด

ต่อยอดจาก **Station v7.7.2** โดยแก้อย่างเดียวคือ **วิธีคำนวณอัตราการไหล**
การตรวจจับหยด หน้าจอ การหมุนจอ เสียงเตือน จังหวะส่ง ESP-NOW และโครงสร้าง
แพ็กเก็ต (Protocol v3) ไม่เปลี่ยนแม้แต่ไบต์เดียว ใช้คู่กับ Host รุ่นเดิมได้ทันที

## ปัญหาที่แก้ (ใหม่ใน v7.7.3)

### อาการ
ตัวเลข mL/h บนจอแกว่งแรง และเมื่อพยาบาลนับหยด 1 นาทีตามคู่มือแล้วเทียบกับจอ
มักได้ผลต่างเกินกรอบ **±10%** ที่คู่มือใช้ตัดสินการคาลิเบรต ทั้งที่เครื่องไม่ได้ผิดอะไร

### สาเหตุ — เฉลี่ย "ส่วนกลับ" ของเวลา

ของเดิมคำนวณอัตราไหลจากหยดแต่ละหยด แล้วเฉลี่ยแบบถ่วงน้ำหนัก

```cpp
instantGttMin   = 60000 / dropDeltaMs;            // อัตรา ณ ขณะนั้น
instantRateMlHr = instantGttMin * 60 / dropFactor;
currentFlowRate_ml_hr = instantRateMlHr * 0.75 + currentFlowRate_ml_hr * 0.25;
```

การเฉลี่ย `1/Δt` มีปัญหาสองข้อพร้อมกัน

1. **เอนสูงเสมอ** — ตามอสมการเจนเซน ค่าเฉลี่ยของส่วนกลับ ≥ ส่วนกลับของค่าเฉลี่ย
   ยิ่งหยดไม่สม่ำเสมอ ค่าที่อ่านได้ยิ่งสูงกว่าความจริง
2. **แกว่งแรง** — น้ำหนัก 0.75 เกาะค่าขณะนั้นเกือบเต็ม ความไม่สม่ำเสมอตามธรรมชาติ
   ของหยดจึงผ่านขึ้นจอเกือบทั้งหมด

ตัวอย่างจริง หยดสลับ 1.0 / 1.4 วินาที (เฉลี่ย 1.2 วินาที = **150 mL/h พอดี** ที่ DF 20)

```
i_a = 60000/1000 = 60.00 gtt/min      i_b = 60000/1400 = 42.86 gtt/min
x_a = 0.75·60.00 + 0.25·x_b  ->  56.57
x_b = 0.75·42.86 + 0.25·x_a  ->  46.28
จอแกว่ง 138.9 - 169.7 mL/h   (กรอบ ±10% คือ 135 - 165)
```

### วิธีแก้ — นับหยดจริงในหน้าต่างเวลา

```cpp
#define RATE_WINDOW_DROPS 8
// N ตัวอย่างเวลา = N-1 ช่วง = มีหยดตกจริง N-1 หยดในช่วงนั้น
mL/h = (N-1) / dropFactor * 3600000 / (t_ใหม่สุด - t_เก่าสุด)
```

เป็นวิธีเดียวกับที่พยาบาลนับหยด 1 นาที และเดียวกับที่ Host บันทึกลง Log รายนาที
(`entry.rateHr = minuteDrops / df * 60`) ตัวเลขทั้งสามจุดจึงตรงกันโดยนิยาม

หน้าต่างจะถูกล้างเมื่อจังหวะการไหลไม่ต่อเนื่องจริง ๆ เท่านั้น

| เหตุ | ทำไม |
|---|---|
| เริ่มถุงใหม่ / กลับจากหยุดชั่วคราว | ช่วงเวลาที่ขาดหายไม่ใช่การไหล |
| ช่วงหยด ≤ 55 ms หรือ ≥ `MAX_OCCLUSION_MS` | ช่วงผิดปกติ ไม่เอามาปน |
| ช่วงหยดต่างจากค่าเฉลี่ยในหน้าต่างเกิน 3 เท่า | พยาบาลหมุนโรลเลอร์แคลมป์ = เปลี่ยนอัตราก้าวกระโดด ทิ้งค่าเก่าทันทีไม่ให้ถ่วงจนตรวจจับช้า |
| ตรวจพบสายพับ | ค่าก่อนสายพับไม่ควรถ่วงค่าหลังแก้สายเสร็จ |

### ผลการทดสอบบนเครื่อง PC

ของจริง 150 mL/h (DF 20) วัดช่วงค่าที่อ่านได้หลังเข้าที่แล้ว

| รูปแบบการหยด | ของจริง | สูตรเดิม | สูตรใหม่ |
|---|---|---|---|
| สม่ำเสมอ 1200 ms | 150.0 | 150.0 – 150.0 ผ่าน | 150.0 – 150.0 ผ่าน |
| สลับ 1000/1400 ms | 150.0 | **138.9 – 169.7 หลุด ±10%** | 146.5 – 153.7 ผ่าน |
| สลับ 800/1600 ms | 150.0 | **135.0 – 202.5 หลุด ±10%** | 143.2 – 157.5 ผ่าน |
| ช้า 9000 ms | 20.0 | 20.0 – 20.0 ผ่าน | 20.0 – 20.0 ผ่าน |

เทียบกับสูตรที่ Host ใช้บันทึก Log: **ต่างกัน 0.000%**

---

## เอกสารเดิมจากรุ่นก่อนหน้า

ต่อยอดจาก **Station v7.7.1** โดยแก้อย่างเดียวคือ **จังหวะการส่งข้อมูลให้ Host**
ส่วนอื่นทั้งหมด (การตรวจจับหยด หน้าจอ การหมุนจอ เสียงเตือน) ไม่เปลี่ยนแม้แต่บรรทัดเดียว

ต่อยอดจาก **Station v7.7.0** (อัลกอริทึมตรวจจับหยดเหมือนเดิมทุกบรรทัด)
เพิ่มเฉพาะ **การหมุนจอ 180 องศา** เพื่อให้ติดตั้งกล่องได้ทั้งแบบสาย USB ลงล่างและขึ้นบน

ตัวอัลกอริทึมต่อยอดจาก **Station v7.5.1** โดยเปลี่ยน **อัลกอริทึมตรวจจับหยด** ทั้งหมด
หน้าจอ 4 หน้า การสื่อสาร ESP-NOW (Protocol v3) และการแจ้งเตือนเหมือนเดิมทุกไบต์
ใช้ผังขาเดิม (เซนเซอร์ที่ GPIO 4) และใช้คู่กับ Host v4.6.0 / v4.7.0 / v4.8.0 / v4.9.x ได้ทันที

## แก้อาการ Host ขึ้น OFFLINE เมื่อมีหลายเตียง (ใหม่ใน v7.7.2)

อาการ: มีหลายเตียงพร้อมกันแล้วจอ Station ยังขึ้น `ONLINE` ปกติ แต่ฝั่ง Host
ขึ้นว่าเตียงนั้น `OFFLINE` เป็นช่วง ๆ ยิ่งเตียงมากยิ่งบ่อย

### สาเหตุจริง — ไม่ใช่สัญญาณอ่อน แต่เป็นจังหวะส่งที่ชนกันค้าง

ของเดิมทุกสเตชันส่งข้อมูลทุก **1000 ms เป๊ะ ไม่มีการสุ่มเลย**

คริสตัลของบอร์ดสองตัวต่างกันราว 40 ppm = คาบส่งเลื่อนหากันเพียง **0.04 ms ต่อวินาที**
เฟรม ESP-NOW ขนาด 23 ไบต์ใช้เวลาออกอากาศราว **0.8 ms** ดังนั้นเมื่อสองเตียงบังเอิญ
ส่งห่างกันไม่ถึง 0.8 ms มันจะชนกัน **ค้างอยู่ราว 40 วินาที** กว่าจะเลื่อนพ้นกัน

```
2 x 0.8 ms / 0.04 ms ต่อวินาที = 40 วินาที
```

40 วินาที นานกว่าเกณฑ์ `ONLINE_TIMEOUT_MS` ของ Host หลายเท่า เตียงนั้นจึงหายไปจากจอ Host

### ทำไมจอ Station ถึงยังขึ้นว่าออนไลน์

Host ส่ง Sync **แยกใบต่อเตียง** มีกี่เตียงก็ส่งเท่านั้นใบต่อวินาที และโค้ดฝั่ง Station
ตั้ง `isHostOnline = true` ทุกใบที่รับได้ ไม่ว่าจะจ่าหน้าถึงเตียงใด (ดู `OnTimeSyncRecv`)

| ทิศทาง | แพ็กเก็ต/วินาที | ต้องหายติดกันกี่ใบจึงขึ้นว่าหลุด |
|---|---|---|
| Host -> Station | เท่าจำนวนเตียง (8 เตียง = 8 ใบ) | 40 ใบ |
| Station -> Host | 1 ใบเสมอ | 5 ใบ (Host รุ่นเดิม) |

ความทนทานต่างกัน 8 เท่า จึงเห็นอาการ "ข้างหนึ่งปกติ อีกข้างหลุด"

### วิธีแก้

```cpp
#define SEND_JITTER_MS  60      // สุ่มคาบส่งในช่วง 940-1060 ms

// หลังส่งทุกครั้ง สุ่มคาบถัดไปใหม่
nextSendDelay = (SEND_INTERVAL_MS - SEND_JITTER_MS) + random(0, 2 * SEND_JITTER_MS + 1);
```

* **สุ่มคาบใหม่ทุกครั้ง** — สองเตียงที่บังเอิญชนกันจะแยกจากกันในรอบถัดไปทันที
  ไม่ใช่รอ 40 วินาที
* **รอบแรกหลังบูตเหลื่อมตามเลขเตียง** (เตียงละ 111 ms) แพ็กเก็ตกระจายกันทั้งวินาที
  ตั้งแต่ต้น ไม่ต้องรอให้ jitter ค่อย ๆ แยก
* **เมล็ดสุ่มมาจาก MAC ของบอร์ด** จึงไม่ซ้ำกันแม้แฟลชเฟิร์มแวร์เดียวกันทุกตัว

อัตราการส่งเฉลี่ยยังเท่าเดิม (1 ใบ/วินาที) โครงสร้างแพ็กเก็ตไม่เปลี่ยน
**ใช้กับ Host รุ่นใดก็ได้ และใช้ปนกับสเตชันรุ่นเก่าได้**

### วัดผลได้

```bash
tools/link-sim/run.sh
```

| จำนวนเตียง | เวลาที่ Host ขึ้น OFFLINE ผิดพลาดใน 1 ชั่วโมง (เดิม) | (ใหม่) |
|---|---|---|
| 2 | 0 วินาที | 0 วินาที |
| 4 | 203 วินาที | **0 วินาที** |
| 6 | 712 วินาที | **0 วินาที** |
| 8 | 407 วินาที | **0 วินาที** |

แนะนำให้อัปเดต Host เป็น [`v4.7.3-OLED`](../**Host จอ OLED v4.7.3**/README.md) ด้วย
ซึ่งแก้ฝั่ง Host อีกสองจุด (เลิกยิง Sync เป็นชุด และวัดคุณภาพลิงก์ให้เห็น)

## สิ่งที่พยาบาลต้องทำ — เหลือ 2 ขั้น

1. หนีบเซนเซอร์ที่กระเปาะ ให้ลำแสงอยู่ **ต่ำกว่าปลายหัวหยดราว 3-5 มม.**
2. เปิดโรลเลอร์ให้น้ำหยด

จบ. ไม่มีเมนู ไม่มีขั้นตอน ไม่ต้องหยุดน้ำเพื่อวัดอะไร เครื่องจะเรียนรู้เองแล้วขึ้นสถานะ

| สถานะบนจอ | ความหมาย | ต้องทำอะไร |
|---|---|---|
| `STARTING` | เพิ่งเปิดเครื่อง กำลังตั้งตัว (ไม่กี่วินาที) | รอ |
| `LEARNING` | เห็นหยดแล้ว กำลังยืนยันจังหวะ | รออีกไม่กี่หยด |
| `READY` | จับหยดได้สม่ำเสมอ พร้อมใช้งาน | ใช้งานได้เลย |
| `CHECK SENSOR` | ไม่เห็นหยดเลยนานผิดปกติ | ขยับตำแหน่งเซนเซอร์ |

ค่าที่เรียนรู้ได้จะถูกบันทึกลง NVS เปิดเครื่องครั้งถัดไปจึงพร้อมใช้งานเร็วขึ้น

## ทำไมถึงเลิกใช้ Wizard ได้

Wizard เดิม (v7.5.x) บังคับให้ผู้ใช้ทำงานแบบวิศวกร — หยุดน้ำเพื่อวัดสัญญาณรบกวน
ดูค่า SNR แล้วตัดสินใจเอง เวอร์ชันนี้ย้ายภาระทั้งหมดไปให้อัลกอริทึม โดยอาศัยข้อเท็จจริง
ทางกายภาพ 3 ข้อของการให้สารน้ำ

1. **หยดเป็นสัญญาณสั้น** (ราว 5-30 ms) บนพื้นหลังที่เปลี่ยนช้ากว่ามาก
2. **หยดมีรูปร่างซ้ำเดิมทุกหยด** จึงเรียนรู้แล้วนำมาใช้เป็นแม่แบบได้
3. **หยดเกิดเป็นจังหวะกึ่งคาบ** จึงยืนยันได้เองว่ากำลังจับของจริงอยู่

## อัลกอริทึม (อยู่ใน `drop_detector.h` — ไม่ผูกกับ Arduino จึงทดสอบบน PC ได้)

```
ADC 2 kHz ─► มีเดียน 5 จุด ─► ค่าเฉลี่ยเคลื่อนที่ W จุด ─► ผลต่างอันดับสอง ─► edge
                                                              │
                          MAD (มัธยฐานแบบสตรีม) ──► sigma ──► เกณฑ์ CFAR = 6·sigma
                                                              │
            edge ─► ชมิตต์ทริกเกอร์ ─► ประตูความกว้าง ─► นับ ─► เรียนรู้ ─► ยืนยันจังหวะ
```

### 1. ผลต่างอันดับสอง — ตัวแก้ปัญหาถุงน้ำเกลือแกว่ง

```
edge(t) = 2·b(t−W) − b(t) − b(t−2W)        เมื่อ b คือค่าเฉลี่ยเคลื่อนที่ W จุด
```

นี่คือ **discrete Laplacian** ซึ่งตัดทั้งค่าคงที่และความชันคงที่ออกโดยโครงสร้าง
เหลือไว้เฉพาะ "ความโค้ง" ที่สเกลเดียวกับความกว้างพัลส์

* การแกว่งของถุงที่ 2 Hz แอมพลิจูด 150 ADC เหลือเพียงราว `A·(ω·Δt)² ≈ 1.7 ADC`
* พัลส์หยดกว้าง 12 ms ผ่านมาได้เต็ม และถูกขยายเป็นราว 2 เท่า

ได้อัตราส่วนแยกแยะราว **100 เท่า** โดยไม่ต้องตั้งเกณฑ์เอง และเพราะ DC ถูกตัดทิ้ง
โดยโครงสร้าง จึงไม่มีอาการ "เส้นฐานค้างจนไม่นับหยด" แบบที่พบใน v7.5.x อีกเลย

### 2. ตัวกรองจับคู่รูปคลื่น — ได้ SNR ฟรีราว 4 เท่า

ทฤษฎีการตรวจจับบอกว่า เมื่อสัญญาณรบกวนเป็นแบบขาว ตัวกรองที่ให้อัตราส่วนสัญญาณ
ต่อสัญญาณรบกวนสูงสุดคือตัวที่มีรูปร่างเหมือนสัญญาณที่จะตรวจจับ (matched filter)
พัลส์หยดมีรูปร่างซ้ำเดิม จึงประมาณด้วยค่าเฉลี่ยเคลื่อนที่ยาวเท่าความกว้างพัลส์
ได้กำไรราว `sqrt(N)` เท่า (N ≈ 19 ตัวอย่าง → ดีขึ้นราว 4.4 เท่า) **โดยไม่ต้องแก้ฮาร์ดแวร์เลย**

ความยาวตัวกรองมาจากความกว้างพัลส์ที่เรียนรู้ไว้ และมีการแก้ค่าที่วัดได้ก่อนนำไปใช้:
ความกว้างที่วัดได้คือความกว้าง ณ ระดับเกณฑ์ ไม่ใช่ความกว้างจริง สำหรับพัลส์ครึ่งไซน์
`w(f) = T·(1 − 2·asin(f)/π)` จึงย้อนกลับไปหา `T` จริงได้ ทำให้ตัวกรองไม่หดตัวลงเรื่อย ๆ

### 3. ประมาณสัญญาณรบกวนด้วยมัธยฐาน — จึงวัดได้ขณะน้ำกำลังหยด

ใช้ตัวติดตามมัธยฐานแบบสตรีม (frugal streaming median) ของ `|edge|` ได้ค่า MAD
แล้วแปลงเป็นค่าเบี่ยงเบนมาตรฐานด้วย `sigma = 1.4826 × MAD`

**จุดสำคัญ:** มัธยฐานไม่ถูกดึงโดยค่าผิดปกติ หยดกินเวลาเพียงไม่กี่เปอร์เซ็นต์ของตัวอย่าง
จึงไม่กระทบค่าที่วัดได้เลย — นี่คือเหตุผลที่ **ไม่ต้องให้ผู้ใช้หยุดน้ำเพื่อวัดพื้นสัญญาณรบกวน**
อีกต่อไป (ต่างจากขั้นที่ 1 ของ wizard เดิมที่ต้องขอให้ "อย่าให้มีหยด")

### 4. เกณฑ์แบบ CFAR — อัตราแจ้งเตือนผิดพลาดคงที่

ตั้งเกณฑ์ที่ `k·sigma` ตามหลัก Constant False Alarm Rate ของงานเรดาร์/โซนาร์
เมื่อ `k = 6` กับสัญญาณรบกวนแบบเกาส์ โอกาสผิดพลาดอยู่ที่ราว `1e-9` ต่อตัวอย่าง
(ที่ 2 kHz คือราว 1 ครั้งต่อ 6 วัน) และอัตรานี้ **คงที่เสมอ** ไม่ว่าสัญญาณรบกวนจะมากหรือน้อย
ผู้ใช้จึงไม่ต้องมาตั้งเกณฑ์เองอีก

### 5. ยืนยันด้วยความสม่ำเสมอของช่วงหยด

เก็บช่วงห่างระหว่างหยด 8 ค่าล่าสุด ถ้ามีอย่างน้อย 4 ค่าที่ต่างจากมัธยฐานไม่เกิน 30%
แปลว่ากำลังจับหยดจริง จึงขึ้นสถานะ `READY` ให้พยาบาลเห็น

ตัวนี้ยังใช้ **ตัดสินทิศสัญญาณเองด้วย**: เริ่มจากทิศที่พบบ่อยที่สุด (หยดบังลำแสง → ค่าลดลง)
ถ้าครบ 10 วินาทีแล้วยังยืนยันจังหวะไม่ได้ ก็สลับทิศแล้วลองใหม่ — เชื่อถือได้กว่า
การวิเคราะห์รูปสัญญาณช่วงสั้น ๆ มาก

## ผลทดสอบ

`tools/detector-test/run.sh` คอมไพล์อัลกอริทึมบนเครื่อง PC แล้วป้อนสัญญาณจำลอง
10 สถานการณ์ โดยไม่ต้องมีบอร์ด เกณฑ์ผ่านคือ **ห้ามนับเกิน** และขาดได้ไม่เกิน 1 หยด
(ข้ามข้อมูล 3 วินาทีแรกที่เครื่องกำลังตั้งตัว)

| สถานการณ์ | คาดหวัง | นับได้ |
|---|---|---|
| นิ่งปกติ | 19 | 19 |
| สัญญาณรบกวนแรง 120 ADC | 19 | 17 |
| หยดจาง (SNR ต่ำ) | 19 | 19 |
| ถุงแกว่ง 2 Hz ±150 ADC | 19 | 19 |
| ถุงแกว่ง 1 Hz ±300 ADC | 19 | 19 |
| ระดับสัญญาณไหล 20 ADC/s | 19 | 19 |
| ระดับสัญญาณไหล 100 ADC/s | 19 | 19 |
| วาดจอบล็อก 40 ms ทุก 150 ms | 11 | 11 |
| พัลส์สองลูกติดกัน (หัว+หางหยด) | 19 | 19 |
| หยดเร็ว 200 หยด/นาที | 57 | 57 |

ไม่มีสถานการณ์ใดที่นับเกิน (ไม่มีการนับเบิ้ล) และกรณีเดียวที่ขาดคือสัญญาณรบกวน
ระดับที่เกินขีดความสามารถของเซนเซอร์เอง (SNR ดิบเพียง 6.4 เท่า)

## หน้าตรวจเซนเซอร์ (สำหรับช่าง — กดปุ่มค้าง 3 วินาที)

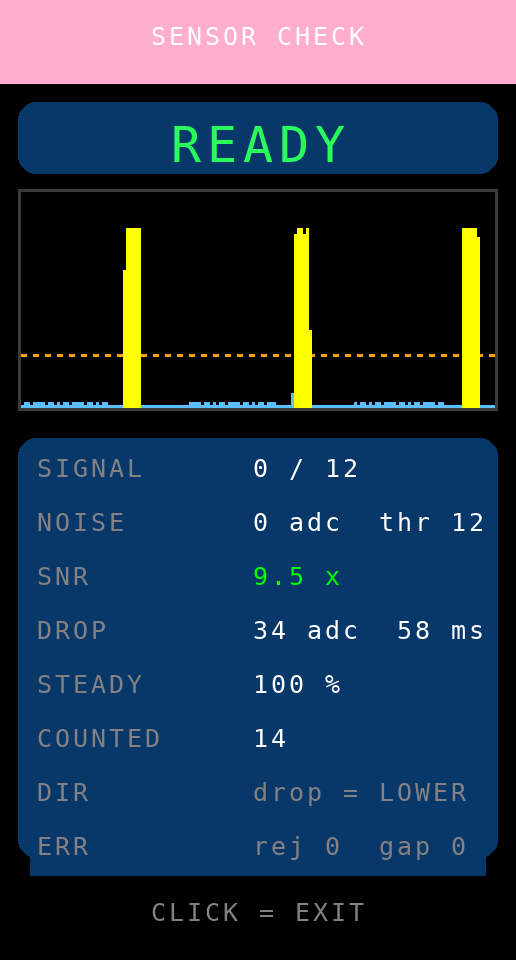
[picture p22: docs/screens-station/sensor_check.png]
หน้าตรวจเซนเซอร์


ดูอย่างเดียว ไม่ต้องทำตามขั้นตอนใด ๆ กดอีกครั้งเพื่อออก

| แถว | ความหมาย |
|---|---|
| `SIGNAL` | ค่าปัจจุบัน / เกณฑ์ที่ใช้อยู่ |
| `NOISE` | สัญญาณรบกวนที่ประมาณได้ และเกณฑ์ |
| `SNR` | อัตราส่วนสัญญาณต่อสัญญาณรบกวน — ต่ำกว่า 3 เท่าควรขยับเซนเซอร์ |
| `DROP` | ความสูง/ความกว้างพัลส์ที่เรียนรู้ไว้ |
| `STEADY` | ความสม่ำเสมอของช่วงหยด (100% = จับจังหวะได้แม่น) |
| `COUNTED` | จำนวนหยดที่นับได้ตั้งแต่เข้าหน้านี้ |
| `DIR` | ทิศสัญญาณที่เครื่องเลือกเอง |
| `ERR` | พัลส์ที่ถูกคัดทิ้ง / จำนวนครั้งที่การอ่านขาดช่วง |

## ค่าที่ปรับได้ (`iv::DetectorConfig` ใน `drop_detector.h`)

| ฟิลด์ | ค่าเริ่มต้น | ปรับเมื่อ |
|---|---|---|
| `cfarK` | 6.0 | ลดลงถ้าหยดจางมากจนจับไม่ได้ (แลกกับโอกาสนับผิดสูงขึ้น) |
| `startWidthMs` | 12 | ความกว้างพัลส์โดยประมาณของเซนเซอร์ที่ใช้ |
| `maxWidthMs` | 150 | เซนเซอร์คืนตัวช้าจนพัลส์กว้างกว่านี้ |
| `rearmMs` | 20 | ยังนับเบิ้ล (แทบไม่ควรต้องปรับ) |
| `polarityTrialMs` | 10000 | เวลาที่ลองแต่ละทิศก่อนสลับ |
| `lockNeeded` | 4 | จำนวนช่วงหยดที่ต้องสม่ำเสมอก่อนขึ้น READY |

## หมุนจอ 180 องศา (ใหม่ใน v7.7.1)

ตอนติดตั้งจริง ทิศที่สายเซนเซอร์และสาย USB ออกจากกล่องเป็นตัวกำหนดว่ากล่องต้องวางท่าไหน
บางตำแหน่งวางแล้วจอกลับหัว เวอร์ชันนี้จึงสลับทิศจอได้ที่หน้าเครื่องโดยไม่ต้องแฟลชใหม่

**วิธีสลับ**

1. คลิกปุ่ม **3 ครั้ง** = เข้าหน้า `SET BED ID`
2. ในหน้านี้ **ดับเบิลคลิก** = สลับ `SCREEN: NORMAL` <-> `SCREEN: FLIP 180`
   จอพลิกให้เห็นผลทันที และบันทึกลง NVS ทันทีเช่นกัน
3. คลิกเดี่ยวยังเป็นการเปลี่ยนเลขเตียง 1-8 เหมือนเดิม ไม่กระทบของเดิม

เปรียบเทียบทิศจอ

ภาพคู่ขวาของแต่ละชุดคือสิ่งที่ออกจากจอเมื่อตั้ง `FLIP 180` — เมื่อพลิกกล่องกลับ
180 องศาตามการติดตั้งจริง จะอ่านได้ตรงตามปกติ

**ตั้งค่าเริ่มต้นตอนคอมไพล์** ถ้าทั้งวอร์ดติดตั้งกลับหัวเหมือนกันหมด แก้บรรทัดเดียว
แล้วแฟลชทีเดียวจบ (ค่าที่เคยตั้งที่หน้าเครื่องจะมีลำดับสูงกว่าเสมอ)

```cpp
#define TFT_ROTATION_DEFAULT  TFT_ROT_FLIP180   // เดิมเป็น TFT_ROT_NORMAL
```

**ทำไมเลย์เอาต์ไม่ต้องแก้แม้แต่บรรทัดเดียว**

จอ ST7789 ขนาด 172x320 ที่ `setRotation(0)` กับ `setRotation(2)` เป็น **แนวตั้ง
ขนาดเท่ากันทั้งคู่** ต่างกันแค่บิต `MX`/`MY` ในรีจิสเตอร์ `MADCTL` ของตัวคอนโทรลเลอร์
คือตัวชิปเป็นผู้กลับลำดับการสแกนแถวและคอลัมน์ให้เอง พิกัด `(x, y)` ทุกจุดที่โค้ดวาด
จึงมีความหมายเหมือนเดิมทั้งหมด (ถ้าเป็น `setRotation(1)` หรือ `(3)` จะกลายเป็นแนวนอน
320x172 ซึ่งต้องรื้อเลย์เอาต์ใหม่ทั้งไฟล์ — จึงไม่ใช้)

อีกจุดที่ต้องระวังคือ **ออฟเซ็ตคอลัมน์** เพราะคอนโทรลเลอร์ ST7789 กว้าง 240 พิกเซล
แต่หน้าจอจริงกว้าง 172 พิกเซล ภาพจึงต้องเลื่อนเข้ามา `(240-172)/2 = 34` พิกเซล
ไลบรารี Adafruit ตั้ง `_colstart = _colstart2 = 34` ให้แล้วเมื่อเรียก `init(172, 320)`
ทั้งสองทิศจึงใช้ออฟเซ็ตเท่ากัน ภาพไม่เลื่อนออกนอกจอ

โค้ดที่เพิ่มจริงมีเท่านี้

```cpp
void applyScreenRotation(uint8_t rot) {
  screenRotation = (rot == TFT_ROT_FLIP180) ? TFT_ROT_FLIP180 : TFT_ROT_NORMAL;
  tft.setRotation(screenRotation);
  tft.setTextWrap(false);
  tft.fillScreen(THEME_BG);
  stateNeedsRedraw = true;      // ให้ทุกหน้าวาดกรอบใหม่ทั้งหน้า
}
```

**ไม่กระทบสิ่งอื่นเลย** — การตรวจจับหยด การสื่อสาร ESP-NOW เสียงเตือน และค่าที่เรียนรู้
ไม่เกี่ยวข้องกับทิศจอแม้แต่จุดเดียว เป็นการเปลี่ยนที่ชั้นแสดงผลล้วน ๆ

## หมายเหตุ

* **ยังไม่ได้ทดสอบบนฮาร์ดแวร์จริง** — สิ่งที่ควรดู: เปิดเครื่องแล้วเปิดโรลเลอร์
  ควรขึ้น `READY` ภายในราว 5-10 วินาที ถ้าค้างที่ `LEARNING` ให้เปิดหน้า SENSOR CHECK
  ดูค่า SNR (ต่ำกว่า 3 เท่า = ต้องขยับเซนเซอร์) และ `ERR` (gap ที่เดินขึ้นเรื่อย ๆ
  แปลว่ามีอะไรกินเวลาในลูปหลักนานผิดปกติ)
* ภาพพรีวิวจากเครื่อง PC สุ่มตัวอย่างได้เพียงราว 500 Hz (จริง 2 kHz) ตัวเลข
  ความสูง/ความกว้างพัลส์ในภาพจึงไม่ตรงกับของจริง แต่พฤติกรรมการนับตรงกัน
* การหมุนจอยังไม่ได้ลองบนบอร์ดจริงเช่นกัน สิ่งที่ควรตรวจคือ ภาพต้องไม่เลื่อน
  ออกนอกขอบจอ (ถ้าเลื่อน แปลว่าโมดูลที่ใช้มีออฟเซ็ตไม่ใช่ 34 — แก้ที่ `tft.init()`)
* คำอธิบายการออกแบบหน้าจอทั้ง 4 หน้าอยู่ใน
  [README ของ v7.5.0](../**Station v7.5.0**/README.md)

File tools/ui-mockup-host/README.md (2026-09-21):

# UI Mockup (Host) — แบบร่างหน้าจอ TFT 2.8" ของเครื่อง Host

จอเป้าหมาย: **ST7789V 240x320 SPI 14 ขา (ไม่มีทัช)** หมุนใช้งานได้ทั้งแนวนอน (320x240) และแนวตั้ง (240x320)

```bash
./run.sh                       # ผลลัพธ์ไปที่ docs/ui-concepts-host/
```

| แบบ | การจัดหน้าจอ | จุดเด่น |
|---|---|---|
| **A BED GRID** | แนวนอน 320x240 — การ์ดเตียง 8 ช่อง | เห็นทุกเตียงพร้อมกันในหน้าเดียว ไม่ต้องกดเปลี่ยนหน้า |
| **B FOCUS** | แนวนอน 320x240 — เตียงที่ต้องดูตัวใหญ่ครึ่งจอ + รายการเตียงอื่น | เตียงที่มีเหตุเด่นชัดที่สุด เห็นค่าละเอียดโดยไม่ต้องกดเข้าไปดู |
| **C BIG LIST** | แนวตั้ง 240x320 — รายการเตียงเรียงลงมา 5 แถว | ตัวหนังสือใหญ่ที่สุด อ่านง่ายจากระยะไกล มีชื่อผู้ป่วยทุกแถว |

ทั้งสามแบบใช้ชุดสีเดียวกับเครื่องประจำเตียง (เขียว = ปกติ, เหลือง = ช้า, ส้ม = เร็ว/ใกล้หมดถุง,
แดง = ไม่มีการไหล, ฟ้า = พักการนับ, เทา = ออฟไลน์) และมีแถบสรุปเหตุการณ์ที่ขอบล่างเสมอ

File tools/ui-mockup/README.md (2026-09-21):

# UI Mockup — แบบร่างหน้าจอ Station 3 แนวทาง

ไฟล์ `station_ui_concepts.cpp` วาดหน้าจอด้วยคำสั่ง Adafruit GFX ชุดเดียวกับเฟิร์มแวร์จริง
แต่คอมไพล์และเรนเดอร์บนเครื่อง PC จึงเปรียบเทียบแบบต่าง ๆ ได้เร็วก่อนลงมือแก้เฟิร์มแวร์

```bash
./run.sh                    # ผลลัพธ์ไปที่ docs/ui-concepts/
```

| แบบ | แนวคิด | เหมาะกับ |
|---|---|---|
| **A — BIG NUMBER** | อัตราไหลตัวใหญ่เต็มจอ + เกจเทียบเป้าหมาย + เวลาที่เหลือ | อ่านค่าจากปลายเตียง/ระยะไกล |
| **B — STATUS CARD** | การ์ดสถานะสี + ไอคอนใหญ่ แล้วตามด้วยตัวเลข 4 ช่อง | ดู "ปกติ/ผิดปกติ" ให้รู้ทันทีโดยไม่ต้องอ่านตัวเลข |
| **C — IV BAG** | ภาพถุงน้ำเกลือที่ระดับน้ำลดลงจริง + กระเปาะหยด + ตัวเลขด้านข้าง | สื่อสารกับผู้ป่วย/ญาติ และดูปริมาณคงเหลือแบบรูปธรรม |

ทั้งสามแบบใช้ข้อความบนจอน้อยที่สุดเท่าที่จำเป็น (ไม่เกิน 10 ชิ้นต่อหน้า) ใช้สีและตำแหน่งแทนคำอธิบาย
และใช้แถบสถานะสีเดียวกันที่ขอบบนเพื่อบอกภาวะของเตียงตั้งแต่แรกเห็น

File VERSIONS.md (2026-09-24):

# สารบัญเวอร์ชัน (Release Index)

ทุกจุดที่เลขเวอร์ชันของสายใดสายหนึ่งขยับ ถูกชี้ตำแหน่งไว้ที่นี่
เพื่อให้ **ย้อนกลับไปใช้ชุดที่สมบูรณ์ชุดไหนก็ได้** โดยไม่ต้องไล่หาคอมมิตเอง

หนึ่งรุ่นคือ **เฟิร์มแวร์ครบทั้งชุด** ทั้งเครื่องประจำเตียงและเครื่องส่วนกลาง
ที่อยู่ด้วยกัน ณ เวลานั้น — ไม่ควรจับคู่ข้ามรุ่น เพราะโครงสร้างแพ็กเก็ต ESP-NOW
(Protocol v3) และรหัสสัญญาณเตือนเปลี่ยนไปในบางรุ่น

ทุกรุ่นถูก push ขึ้น GitHub ไว้เป็น **branch** ใต้โฟลเดอร์ `release/`
กดโหลดเป็นไฟล์ zip จากตารางข้างล่างได้เลย ไม่ต้องใช้คำสั่ง git

## สายผลิตภัณฑ์

| สาย | โฟลเดอร์บน `main` | อุปกรณ์ | จอ |
|---|---|---|---|
| Station | `firmware/Station/` | เครื่องประจำเตียง | TFT ในตัว |
| Station สายเสถียร | `firmware/Station-Stable/` | เครื่องประจำเตียง รุ่นอัลกอริทึมเดิม | TFT ในตัว |
| Station บอร์ดเล็ก | `firmware/Station-C3-OLED/` | เครื่องประจำเตียง บอร์ด ESP32-C3 | OLED 0.42" 72×40 |
| Host OLED | `firmware/Host-OLED/` | เครื่องส่วนกลาง | SH1106 128×64 |
| Host TFT 2.8" | `firmware/Host-TFT28/` | เครื่องส่วนกลาง | ST7789V 320×240 แนวนอน |
| Host สัมผัส 2.4" | `firmware/Host-Touch24/` | เครื่องส่วนกลาง | ILI9341 + XPT2046 240×320 แนวตั้ง |

เลือก Host **หนึ่งตัว** ตามชนิดจอที่มี ใช้คู่กับ Station สายใดสายหนึ่ง

## โครงสร้าง branch

```
main                          branch หลัก งานล่าสุดทั้งหมดอยู่ที่นี่
release/00-h4.7.0              หมุดเวลาของแต่ละรุ่น ห้ามแก้ ห้าม push ทับ
release/01-s7.5.0-h4.7.0       
release/02-s7.5.0-h4.7.0-tft4.8.0 
release/03-s7.5.0-h4.7.0-touch4.9.0 
release/04-s7.6.0-h4.7.0       
release/05-s7.6.0-h4.7.0-lts7.5.1 
release/06-s7.7.0-h4.7.0       
release/07-s7.7.0-h4.7.1       
release/08-s7.7.0-h4.7.2       
release/09-s7.7.1-h4.7.2       
release/10-s7.7.1-h4.7.2-lts7.5.2 
release/11-s7.7.2-h4.7.3-lts7.5.3 
release/12-s7.7.2-h4.7.4       
release/13-s7.7.3-h4.7.5-lts7.5.4 
release/14-s7.7.3-h4.7.5-touch4.9.2 
release/15-s7.7.3-h4.7.6       
release/16-s7.8.0-h4.7.7-lts7.5.5-tft4.8.1-touch4.9.3 
release/17-s7.8.0-h4.7.7-c3v1.0.0 
```

> **branch เหล่านี้ห้ามแก้และห้าม push ทับ** ให้ถือเป็นหมุดเวลาอย่างเดียว
> งานที่พัฒนาต่ออยู่ที่ `main`
>
> ปกติงานลักษณะนี้ควรเป็น **tag** ไม่ใช่ branch แต่บัญชีที่เซสชันนี้ใช้
> push `refs/tags/*` และลบ ref ไม่ได้ เซิร์ฟเวอร์ตอบ 403 จึงใช้ branch แทน
> ได้ผลเหมือนกันทุกอย่างสำหรับการย้อนกลับ

## ตารางรุ่น

| ชื่อรุ่น | Station | สายเสถียร | บอร์ดเล็ก | OLED | TFT 2.8" | สัมผัส 2.4" | คอมไพล์ | โหลด zip | คอมมิต | สาระสำคัญ |
|---|---|---|---|---|---|---|---|---|---|---|
| `release/00-h4.7.0` | — | — | — | 4.7.0 | — | — | ❔ | [zip](https://github.com/kittiphun-rut/IV-Monitor-BCNPH/archive/refs/heads/release/00-h4.7.0.zip) | [`676b321`](https://github.com/kittiphun-rut/IV-Monitor-BCNPH/tree/676b3212e3802170e3a465e4a2b30d57e656920e) | host: AP-only mode (remove Wi-Fi management) + station UI concepts<br><sub>16/9/2026</sub> |
| `release/01-s7.5.0-h4.7.0` | — | 7.5.0 | — | 4.7.0 | — | — | ❔ | [zip](https://github.com/kittiphun-rut/IV-Monitor-BCNPH/archive/refs/heads/release/01-s7.5.0-h4.7.0.zip) | [`4a7dc3b`](https://github.com/kittiphun-rut/IV-Monitor-BCNPH/tree/4a7dc3b69df2e936c5aa88662564b3b79e162c23) | station: redesign TFT UI (IV BAG concept) + 30-min flow trend page<br><sub>12/9/2026</sub> |
| `release/02-s7.5.0-h4.7.0-tft4.8.0` | — | 7.5.0 | — | 4.7.0 | 4.8.0 | — | ❔ | [zip](https://github.com/kittiphun-rut/IV-Monitor-BCNPH/archive/refs/heads/release/02-s7.5.0-h4.7.0-tft4.8.0.zip) | [`f21c6d0`](https://github.com/kittiphun-rut/IV-Monitor-BCNPH/tree/f21c6d024162cf8494244af1e6ed526395f204c0) | host: new 2.8" TFT build (v4.8.0-TFT) with FOCUS dashboard<br><sub>12/9/2026</sub> |
| `release/03-s7.5.0-h4.7.0-touch4.9.0` | — | 7.5.0 | — | 4.7.0 | 4.8.0 | 4.9.0 | ❔ | [zip](https://github.com/kittiphun-rut/IV-Monitor-BCNPH/archive/refs/heads/release/03-s7.5.0-h4.7.0-touch4.9.0.zip) | [`ef8f433`](https://github.com/kittiphun-rut/IV-Monitor-BCNPH/tree/ef8f4330fb822c86399dc377f36e742e591f3931) | host: touch-screen build v4.9.0-TOUCH (2.4" 240x320 + XPT2046)<br><sub>12/9/2026</sub> |
| `release/04-s7.6.0-h4.7.0` | 7.6.0 | 7.5.0 | — | 4.7.0 | 4.8.0 | 4.9.0 | ❔ | [zip](https://github.com/kittiphun-rut/IV-Monitor-BCNPH/archive/refs/heads/release/04-s7.6.0-h4.7.0.zip) | [`4aec24a`](https://github.com/kittiphun-rut/IV-Monitor-BCNPH/tree/4aec24a05f957f75e47072860ebf75379ee47ad6) | station: รองรับเซ็นเซอร์หยดแบบเอาต์พุตดิจิทัล + ผังขาใหม่ (v7.6.0)<br><sub>12/9/2026</sub> |
| `release/05-s7.6.0-h4.7.0-lts7.5.1` | 7.6.0 | 7.5.1 | — | 4.7.0 | 4.8.0 | 4.9.0 | ❔ | [zip](https://github.com/kittiphun-rut/IV-Monitor-BCNPH/archive/refs/heads/release/05-s7.6.0-h4.7.0-lts7.5.1.zip) | [`c27be5a`](https://github.com/kittiphun-rut/IV-Monitor-BCNPH/tree/c27be5a8bc8c43b8abffe6734a1b41f7dbb1efe8) | station: รื้อระบบคัดกรองหยดและหน้าคาลิเบรตใหม่ (v7.5.1)<br><sub>12/9/2026</sub> |
| `release/06-s7.7.0-h4.7.0` | 7.7.0 | 7.5.1 | — | 4.7.0 | 4.8.0 | 4.9.0 | ❔ | [zip](https://github.com/kittiphun-rut/IV-Monitor-BCNPH/archive/refs/heads/release/06-s7.7.0-h4.7.0.zip) | [`eba3f61`](https://github.com/kittiphun-rut/IV-Monitor-BCNPH/tree/eba3f6159a6058cffcdaab578883022210cdead0) | station: ไม่ต้องคาลิเบรตด้วยมืออีกต่อไป (v7.7.0)<br><sub>12/9/2026</sub> |
| `release/07-s7.7.0-h4.7.1` | 7.7.0 | 7.5.1 | — | 4.7.1 | 4.8.0 | 4.9.0 | ❔ | [zip](https://github.com/kittiphun-rut/IV-Monitor-BCNPH/archive/refs/heads/release/07-s7.7.0-h4.7.1.zip) | [`5140a94`](https://github.com/kittiphun-rut/IV-Monitor-BCNPH/tree/5140a94dd1674dc8e5fc29161bc16ad3c665de76) | host(oled): รองรับ Station v7.5.1 และ v7.7.0 + เตือนเซนเซอร์ยังไม่จับหยด (v4.7.1-OLED)<br><sub>12/9/2026</sub> |
| `release/08-s7.7.0-h4.7.2` | 7.7.0 | 7.5.1 | — | 4.7.2 | 4.8.0 | 4.9.0 | ❔ | [zip](https://github.com/kittiphun-rut/IV-Monitor-BCNPH/archive/refs/heads/release/08-s7.7.0-h4.7.2.zip) | [`1b1dd84`](https://github.com/kittiphun-rut/IV-Monitor-BCNPH/tree/1b1dd843a6be87c5a37b6031f102a3d4e948c51f) | host(oled): ปรับหน้าเว็บ Dashboard ตามที่พยาบาลขอ (v4.7.2-OLED)<br><sub>18/9/2026</sub> |
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

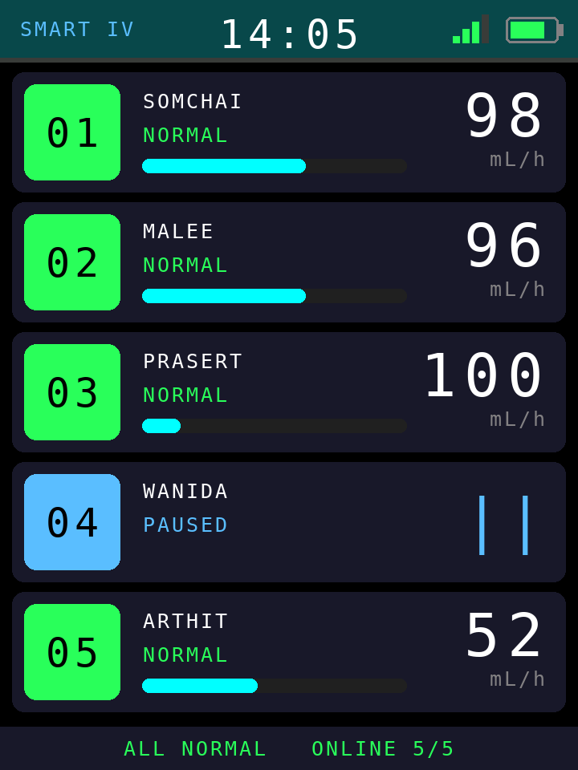
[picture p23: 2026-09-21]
docs/ui-concepts-host/C1_normal.png

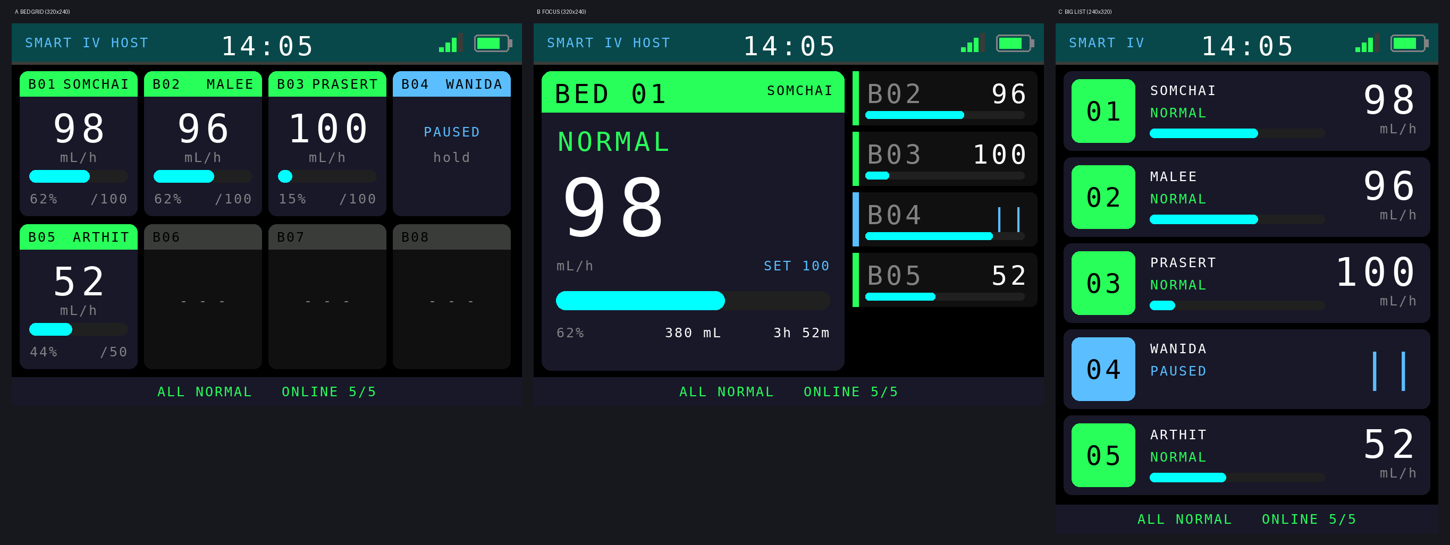
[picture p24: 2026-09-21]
docs/ui-concepts-host/compare_normal.png

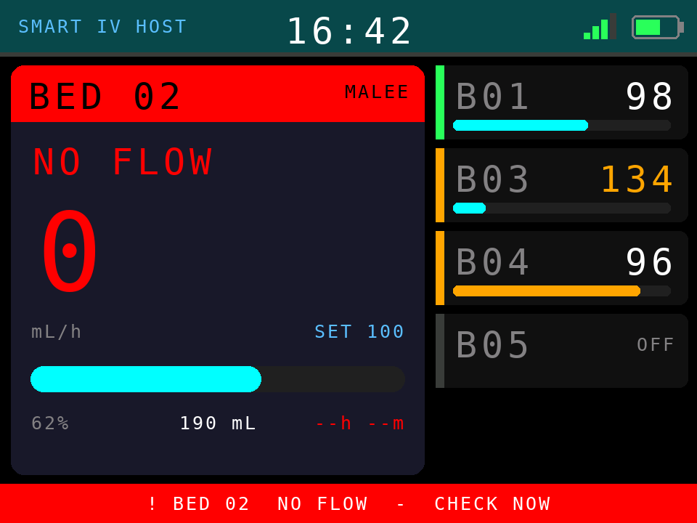
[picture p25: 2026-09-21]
docs/ui-concepts-host/B2_alert.png

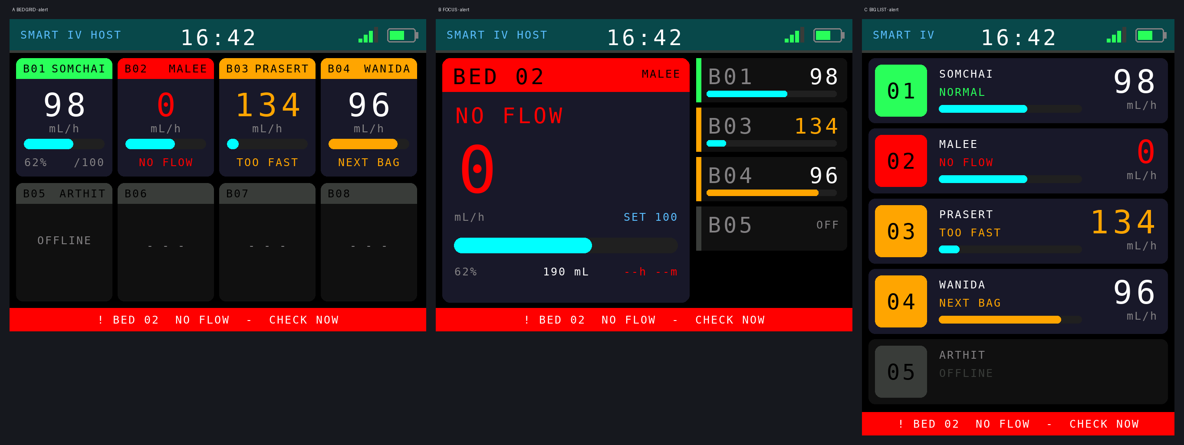
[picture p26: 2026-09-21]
docs/ui-concepts-host/compare_alert.png

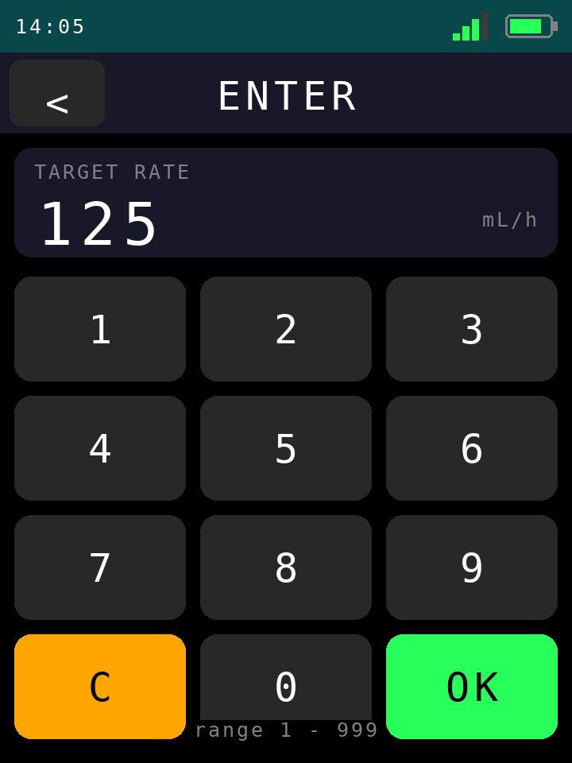
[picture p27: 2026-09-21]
docs/ui-concepts-touch/t5_numpad.png

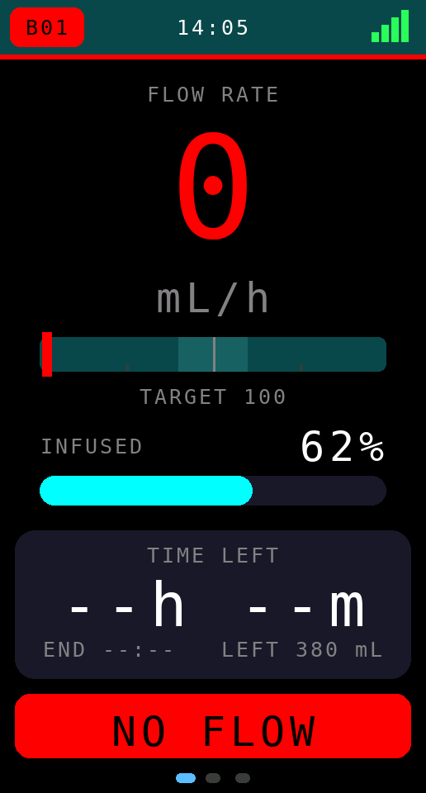
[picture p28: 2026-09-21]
docs/ui-concepts/A2_alert.png

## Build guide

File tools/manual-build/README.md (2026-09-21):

# เครื่องมือสร้างคู่มือพยาบาล

สร้างไฟล์ `docs/คู่มือพยาบาล_Smart_IV_Alert.docx` ตามรูปแบบเอกสารราชการไทย

```bash
tools/manual-build/run.sh
```

## รูปแบบที่ใช้

| รายการ | ค่าที่ตั้ง |
|---|---|
| ขนาดกระดาษ | A4 |
| ขอบกระดาษ | บน ๑.๕ นิ้ว · ซ้าย ๑.๕ นิ้ว · ขวา ๑ นิ้ว · ล่าง ๑ นิ้ว |
| แบบอักษร | TH SarabunPSK ขนาด ๑๖ พอยต์ (หัวข้อ ๑๘-๒๐ พอยต์ ตัวหนา) |
| เลขหน้า | มุมบนขวา — ส่วนนำใช้พยัญชนะไทย (ก ข ค ง) เนื้อหาใช้เลขอารบิกเริ่มที่ ๑ |
| โครงเล่ม | ปก · คำนำ · สารบัญ · สารบัญตาราง · สารบัญภาพ · บทที่ ๑-๗ · ภาคผนวก ก-จ · เอกสารอ้างอิง |

## สารบัญอัตโนมัติ

สารบัญ สารบัญตาราง และสารบัญภาพ เป็น **ฟิลด์ TOC จริงของ Word** ทั้งสามชุด

| คำสั่งในฟิลด์ | เก็บรายการจาก |
|---|---|
| `TOC \o "1-2" \h \z \u` | หัวข้อระดับ ๑ และ ๒ (ชื่อบท และหัวข้อย่อย) |
| `TOC \t "CaptionTable,3" \h \z` | ย่อหน้าที่ใช้สไตล์ `CaptionTable` (คำบรรยายเหนือตาราง) |
| `TOC \t "CaptionFigure,3" \h \z` | ย่อหน้าที่ใช้สไตล์ `CaptionFigure` (คำบรรยายใต้ภาพ) |

### วิธีอัปเดตสารบัญ

* **เปิดไฟล์** — ตั้ง `updateFields` ไว้แล้ว Word จะถามหรืออัปเดตให้เองตั้งแต่ตอนเปิด
* **สั่งเอง** — กด `Ctrl+A` แล้วกด `F9` หรือคลิกขวาที่สารบัญแล้วเลือก Update Field
* เลือก "Update entire table" เพื่อสร้างรายการใหม่ทั้งหมด

### ทำไมยังต้องคำนวณเลขหน้าเองอีก

ฟิลด์ TOC ที่สร้างเปล่า ๆ จะว่างจนกว่าผู้ใช้จะสั่งอัปเดต ถ้าใครเปิดแล้วสั่งพิมพ์เลยจะได้หน้าว่าง
สคริปต์นี้จึงฝัง **ผลลัพธ์ที่คำนวณไว้ล่วงหน้า** ไว้ในฟิลด์ด้วย (เหมือนที่ Word ทำเวลาบันทึกไฟล์เอง)

* เปิดแล้วพิมพ์ได้ทันที เพราะมีรายการและเลขหน้าครบอยู่แล้ว
* สั่งอัปเดตเมื่อไรก็ได้ Word จะสร้างใหม่จากเนื้อหาจริงในเล่ม

ขั้นตอนใน `run.sh` จึงเป็น

1. สร้าง .docx แล้วให้ `inject_toc_field.py` แปลงสัญลักษณ์เป็นฟิลด์ TOC จริง
2. แปลงเป็น PDF แล้วให้ `resolve_pages.py` อ่านว่าแต่ละหัวข้ออยู่หน้าใดจริง
3. สร้างใหม่โดยฝังเลขหน้าที่ได้ แล้วแปลงเป็นฟิลด์อีกครั้ง
4. ตรวจซ้ำว่าเลขหน้าไม่เปลี่ยนแล้ว (สคริปต์แจ้งผลให้)

### รูปแบบต้องไม่เพี้ยนหลังอัปเดต

เมื่อ Word สร้างสารบัญใหม่ มันจะจัดรูปแบบบรรทัดด้วยสไตล์ชื่อ `TOC 1` ถึง `TOC 9`
ถ้าไม่กำหนดไว้ Word จะใช้ค่าปริยายของตัวเอง (Calibri ๑๑ พอยต์) ซึ่งผิดรูปแบบราชการทันที
`build_manual.js` จึงกำหนดสไตล์เหล่านี้ไว้ให้แล้ว

| สไตล์ | ใช้กับ | รูปแบบ |
|---|---|---|
| `TOC 1` | ชื่อบทและภาคผนวก | TH SarabunPSK ๑๖ พอยต์ ตัวหนา ไม่เยื้อง |
| `TOC 2` | หัวข้อย่อย | ๑๖ พอยต์ ธรรมดา เยื้อง ๐.๓๕ นิ้ว |
| `TOC 3` | รายการตารางและภาพ | ๑๖ พอยต์ ธรรมดา ไม่เยื้อง |

ทุกสไตล์ตั้งแท็บชิดขวาพร้อมจุดไข่ปลาไว้ที่ขอบขวาของเนื้อที่พิมพ์ (๘๓๐๖ ทวิป)

### หมายเหตุเรื่องหัวบท

หัวบทเป็น **ย่อหน้าเดียว** ที่แสดงผลสองบรรทัด (ใช้ตัวขึ้นบรรทัดใหม่ภายในย่อหน้า)
เพราะสารบัญอัตโนมัติดึงข้อความจากทั้งย่อหน้า ถ้าแยกเป็นสองย่อหน้าจะได้แค่ "บทที่ ๑"
โดยไม่มีชื่อบทตามมา

## ลำดับชั้นหัวข้อ

ทุกหัวข้อใช้สไตล์ Heading จริงของ Word จึงแสดงใน Navigation Pane และเก็บเข้าสารบัญได้เอง

| ระดับ | สไตล์ | รูปแบบ | ตัวอย่าง |
|---|---|---|---|
| ๑ | Heading 1 | ๒๐ พอยต์ ตัวหนา กลางหน้า ขึ้นหน้าใหม่ | บทที่ ๔ / การติดตั้งเซนเซอร์และการคาลิเบรต |
| ๒ | Heading 2 | ๑๘ พอยต์ ตัวหนา ชิดซ้าย | ๔.๕ รุ่นคาลิเบรตเอง (๗.๕.x) |
| ๓ | Heading 3 | ๑๖ พอยต์ ตัวหนา เยื้อง ๐.๓๕ นิ้ว | ๔.๕.๑ ขั้นที่ ๑ NOISE |
| เนื้อความ | Normal | ๑๖ พอยต์ ย่อหน้าแรกเยื้อง ๐.๔ นิ้ว | — |

หัวข้อระดับ ๓ ใส่เลขลำดับเต็มทุกอัน (เช่น ๔.๕.๑) เพื่อให้รู้ทันทีว่าอยู่ใต้หัวข้อใด
สารบัญเก็บเฉพาะระดับ ๑ และ ๒ (`TOC \\o "1-2"`) เพื่อไม่ให้ยาวเกินไป

## ฉบับข้อความล้วน (.txt)

`run.sh` สร้าง `docs/คู่มือพยาบาล_Smart_IV_Alert.txt` ให้อัตโนมัติทุกครั้ง
โดย `make_plaintext.py` อ่านจากไฟล์ .docx ที่เสร็จแล้ว เนื้อหาจึงตรงกับเล่มจริงเสมอ

| สิ่งที่แสดง | รูปแบบในไฟล์ข้อความ |
|---|---|
| บท | ข้อความคร่อมด้วยเส้น `=` เต็มความกว้าง |
| หัวข้อระดับ ๒ | ข้อความแล้วขีดเส้น `-` ใต้บรรทัด |
| หัวข้อระดับ ๓ | เยื้องเข้าไป แล้วขีดเส้น `~` ใต้บรรทัด |
| ตาราง | ตารางเส้น ASCII จัดคอลัมน์ตามสัดส่วนเนื้อหา |
| ภาพ | บรรทัด `[ภาพ] ภาพที่ N ...` |
| บรรทัดสารบัญ | ข้อความ จุดไข่ปลา แล้วเลขหน้า |

การตัดบรรทัดภาษาไทยใช้ `pythainlp` ตัดคำถ้ามีติดตั้งอยู่ จึงไม่ตัดกลางคำ
ถ้าไม่มี จะยอมให้บรรทัดยาวเกินแทนการตัดคำผิด (ไม่ถือเป็นข้อผิดพลาด)

ความกว้างปริยาย ๗๘ ตัวอักษร เปลี่ยนได้ด้วยอาร์กิวเมนต์ที่สาม

```bash
python3 make_plaintext.py ไฟล์.docx ไฟล์.txt 100
```

## ข้อควรทราบเรื่องแบบอักษร

เครื่องที่ใช้สร้างเอกสารนี้**ไม่มี TH SarabunPSK ติดตั้งอยู่** ตัวเอกสารระบุชื่อฟอนต์ไว้ถูกต้องแล้ว
และจะแสดงผลถูกต้องบนเครื่องที่มีฟอนต์นี้ (เครื่องราชการไทยทั่วไปมีอยู่แล้ว)
แต่ PDF ตัวอย่างและเลขหน้าใน `pagemap.json` คำนวณจากการเรนเดอร์ด้วยฟอนต์แทน (Loma)
ซึ่ง **กว้างกว่า** TH SarabunPSK เล็กน้อย

ดังนั้นเมื่อเปิดด้วย Word บนเครื่องที่มี TH SarabunPSK จริง ควร

1. ตรวจว่าเลขหน้าในสารบัญตรงกับเล่ม หากคลาดเคลื่อน ให้แก้ตัวเลขในสารบัญโดยตรง
2. หรือรัน `run.sh` ใหม่บนเครื่องที่ติดตั้ง TH SarabunPSK แล้ว เลขหน้าจะถูกคำนวณใหม่ให้เอง

## ไฟล์ในโฟลเดอร์นี้

| ไฟล์ | หน้าที่ |
|---|---|
| `manual_lib.js` | ตัวช่วยจัดรูปแบบ (ย่อหน้า หัวข้อ ตาราง ภาพ กล่องคำเตือน บรรทัดสารบัญ) |
| `part_front.js` | ปก คำนำ สารบัญ สารบัญตาราง สารบัญภาพ |
| `part_ch12.js` | บทที่ ๑ บทนำ และบทที่ ๒ ความรู้ทั่วไปเกี่ยวกับระบบ |
| `part_ch34.js` | บทที่ ๓ ขั้นตอนการปฏิบัติงาน และบทที่ ๕ สัญญาณเตือน |
| `part_calib.js` | บทที่ ๔ การติดตั้งเซนเซอร์และการคาลิเบรต |
| `part_ch56.js` | บทที่ ๖ การแก้ไขปัญหา และบทที่ ๗ การบำรุงรักษา |
| `part_appendix.js` | ภาคผนวก ก-จ และเอกสารอ้างอิง |
| `build_manual.js` | ประกอบทุกส่วนเป็นไฟล์ .docx |
| `resolve_pages.py` | อ่านเลขหน้าจริงจาก PDF |
| `inject_toc_field.py` | แปลงสัญลักษณ์เป็นฟิลด์ TOC จริงพร้อมผลลัพธ์แคช |
| `make_plaintext.py` | แปลงเล่มที่เสร็จแล้วเป็นไฟล์ข้อความล้วน |
| `make_images.py` | เตรียมภาพประกอบจากภาพหน้าจอที่เครื่องมือ preview สร้างไว้ |
| `manual-img/` | ภาพประกอบที่ใช้ในเล่ม |

## เมื่อแก้เนื้อหาคู่มือ

แก้ในไฟล์ `part_*.js` แล้วรัน `run.sh` ใหม่ เลขหน้าในสารบัญจะถูกปรับให้เองโดยอัตโนมัติ

### ข้อควรระวังเวลาแก้ `build_manual.js`

ต้องเรียก `L.setPageMap()` **ก่อน** `require` ไฟล์เนื้อหาเสมอ
เพราะบรรทัดสารบัญถูกสร้างตั้งแต่ตอนโหลดโมดูล ถ้าตั้งตารางเลขหน้าทีหลัง
`toc()` จะถูกเรียกไปแล้วด้วยตารางเปล่า แล้วตกไปใช้เลขหน้าสำรองที่เขียนไว้ในโค้ด
ซึ่งทำให้กลไกสองรอบไม่ทำงานโดยไม่มีอะไรแจ้งเตือน

### การเน้นข้อความ

ในข้อความของ `p()` `plain()` และ `item()` ใช้ `**ข้อความ**` เพื่อทำตัวหนาได้
(`runsFrom()` ใน `manual_lib.js` แปลงให้) ถ้าไม่มีตัวช่วยนี้ ดอกจันจะติดไปบนหน้ากระดาษจริง

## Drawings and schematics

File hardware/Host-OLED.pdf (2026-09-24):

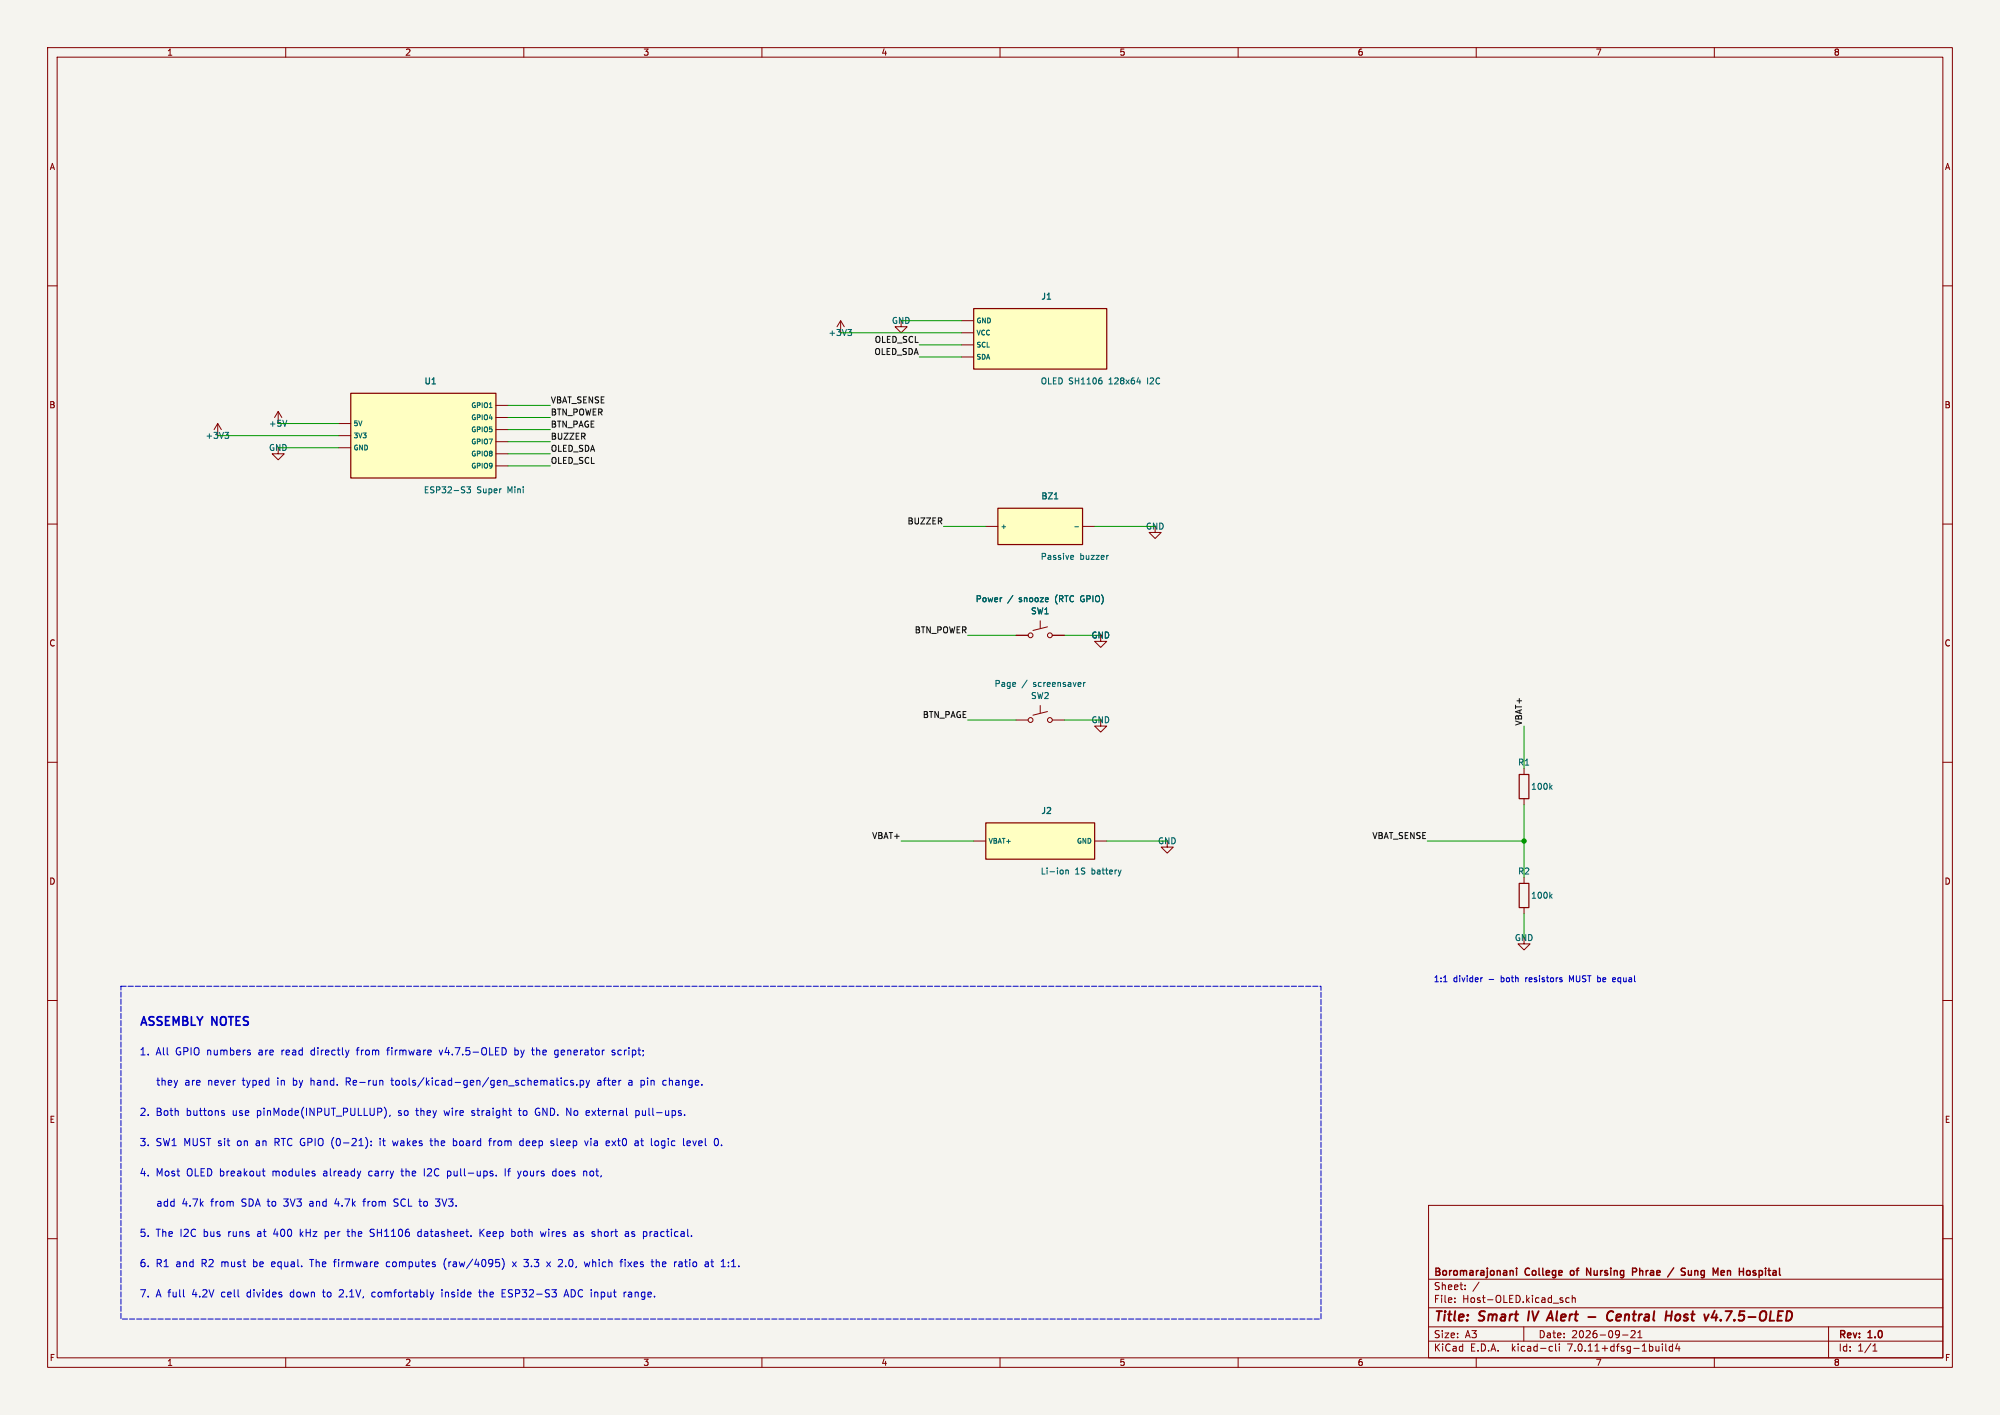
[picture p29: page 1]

SW1 Power / snooze (RTC GPIO) 3V3

SW1 Power / snooze (RTC GPIO) GND

Id: 1/1 Title: Smart IV Alert - Central Host v4.7.5-OLED

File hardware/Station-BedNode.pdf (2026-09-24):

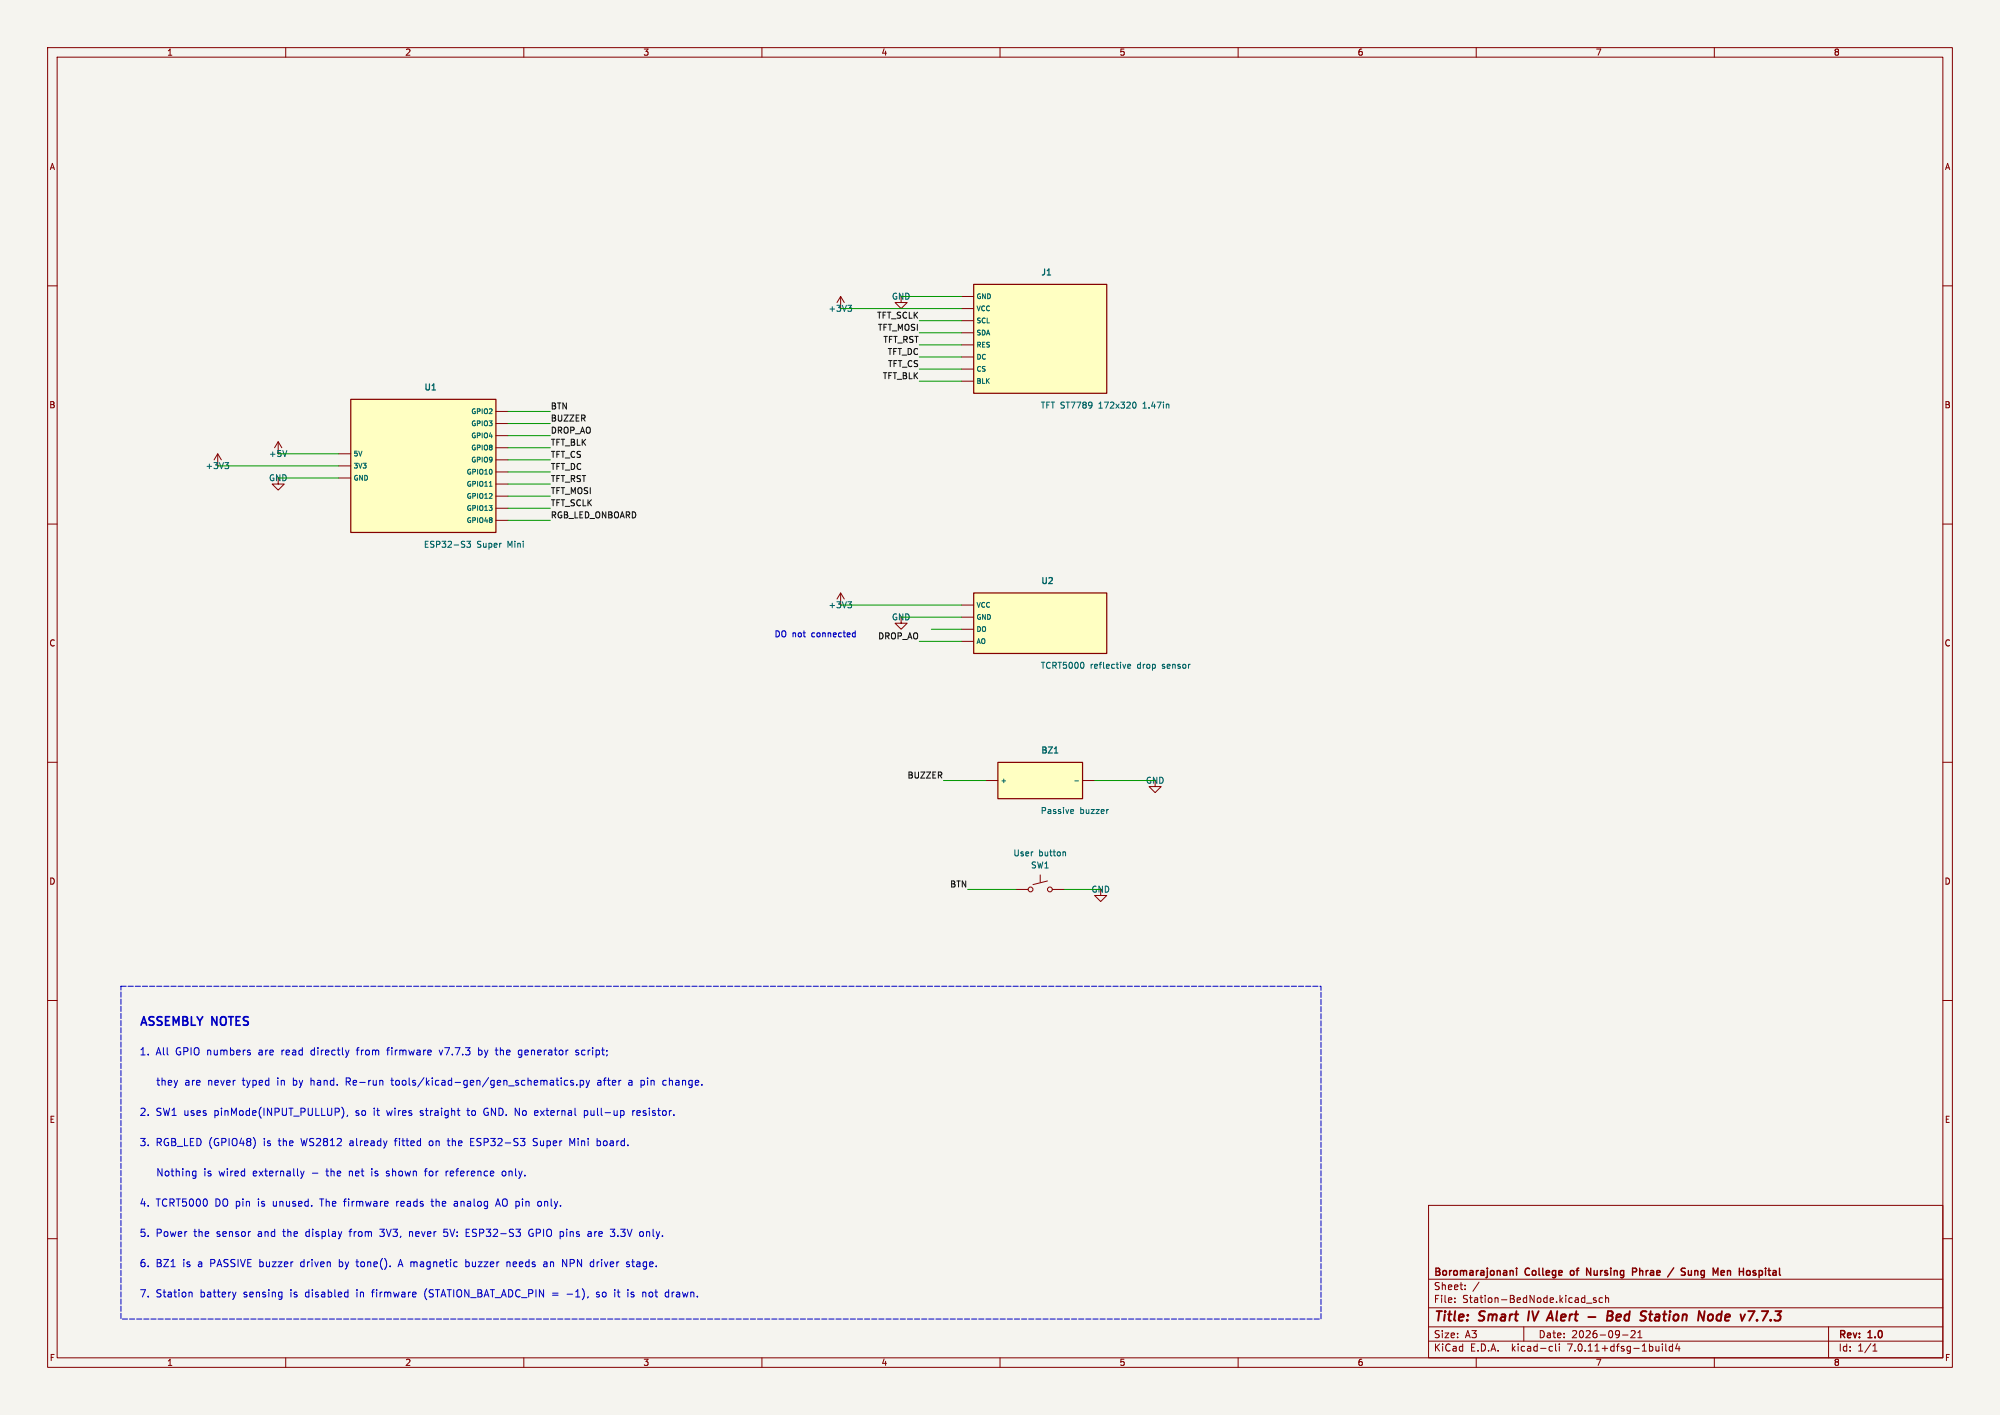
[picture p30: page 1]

VCC
SCL SDA RES DC

Id: 1/1 Title: Smart IV Alert - Bed Station Node v7.7.3

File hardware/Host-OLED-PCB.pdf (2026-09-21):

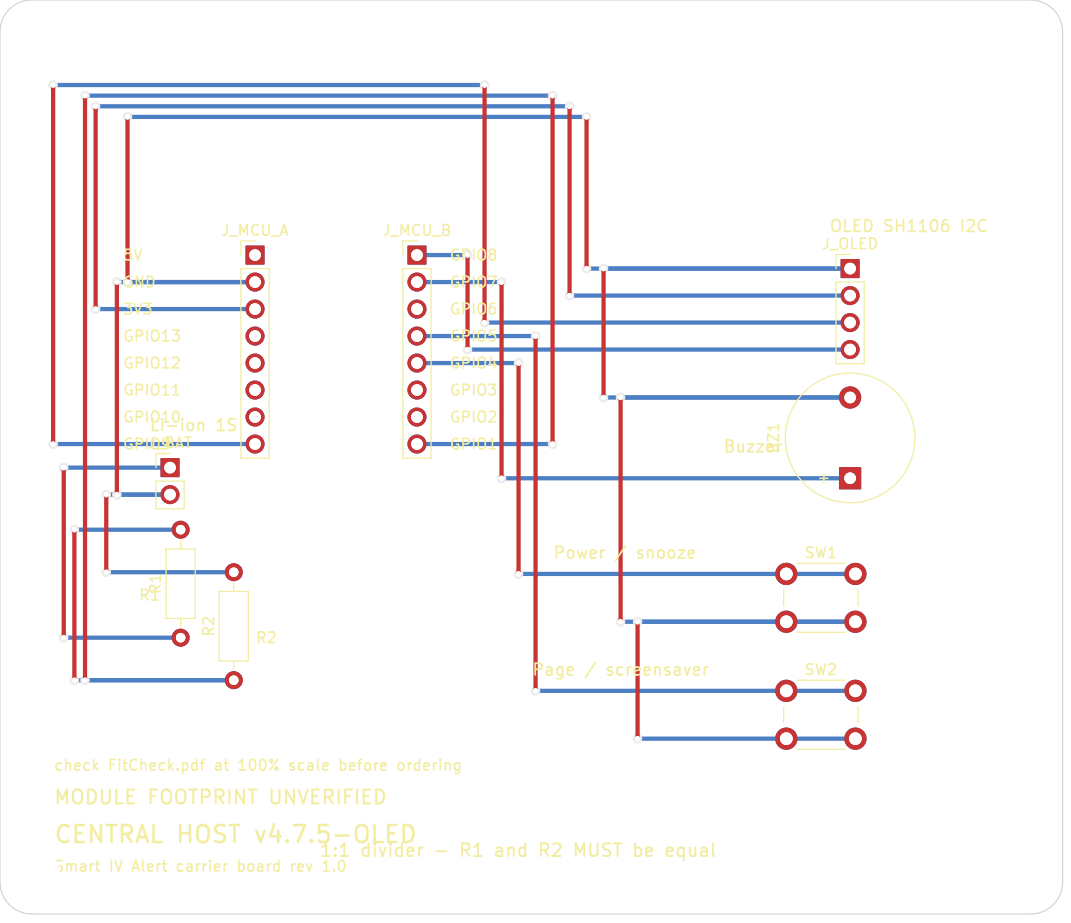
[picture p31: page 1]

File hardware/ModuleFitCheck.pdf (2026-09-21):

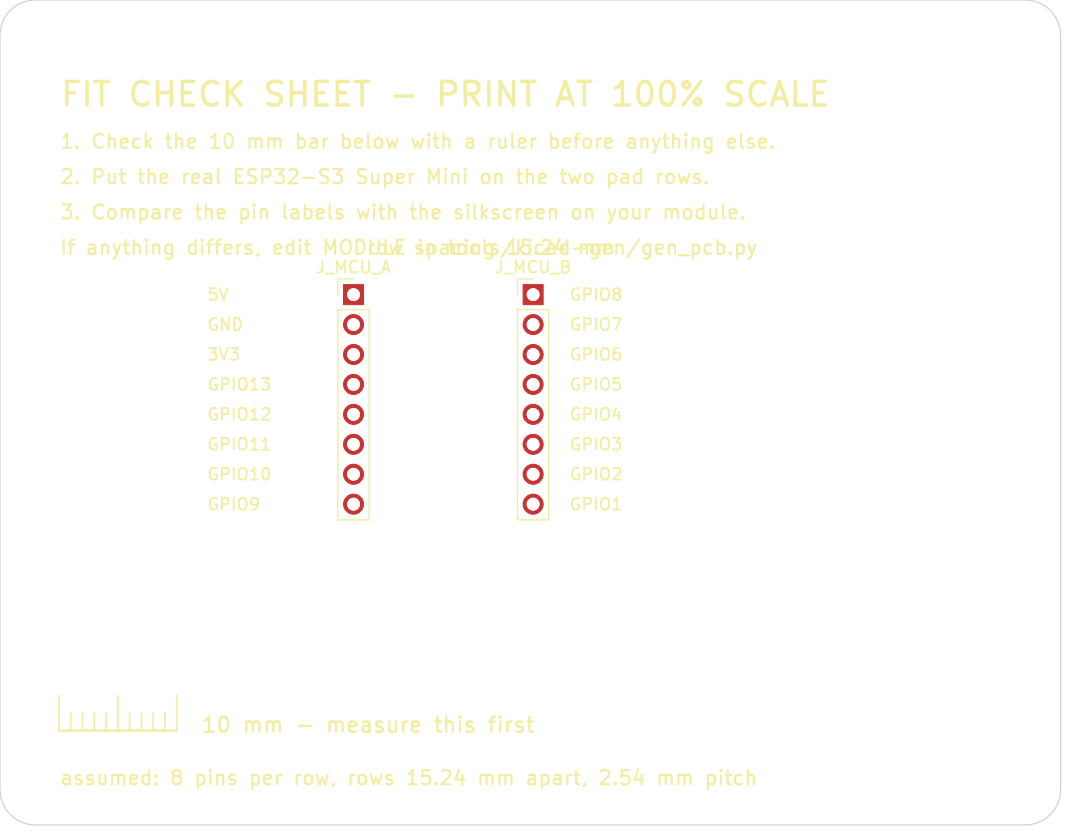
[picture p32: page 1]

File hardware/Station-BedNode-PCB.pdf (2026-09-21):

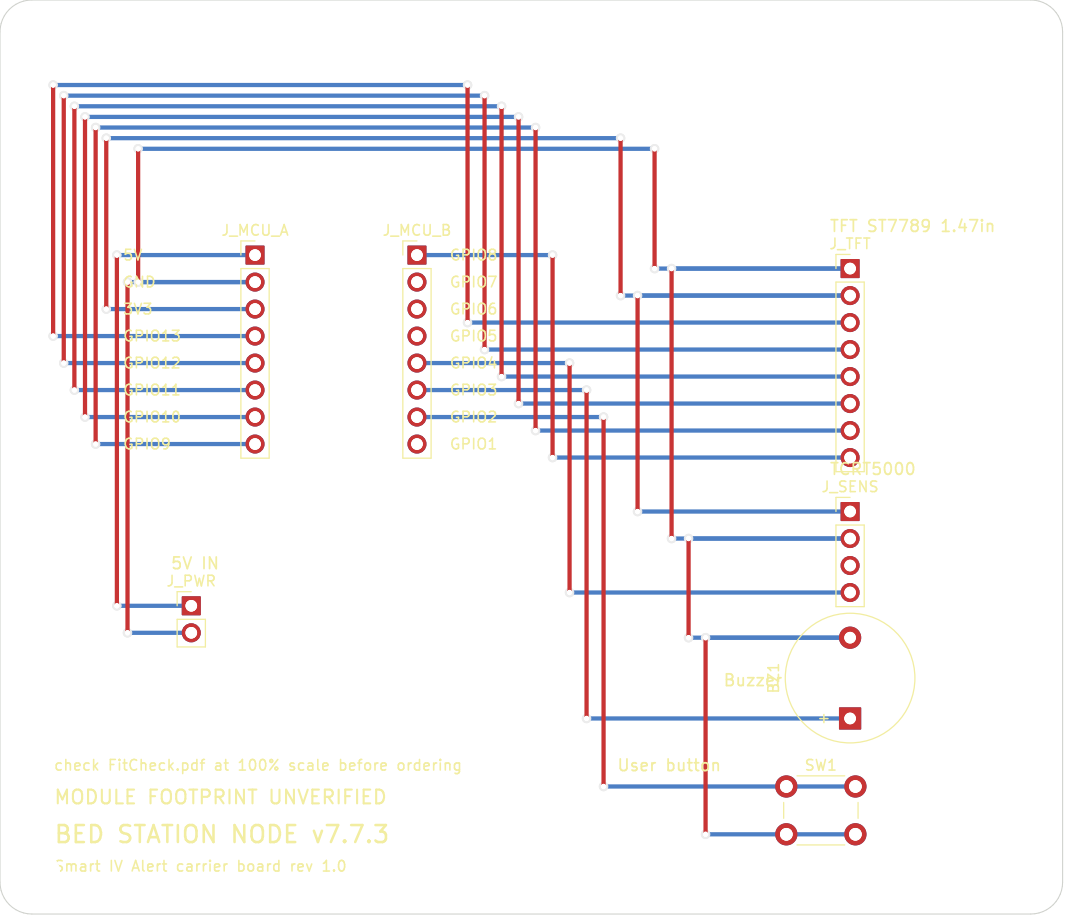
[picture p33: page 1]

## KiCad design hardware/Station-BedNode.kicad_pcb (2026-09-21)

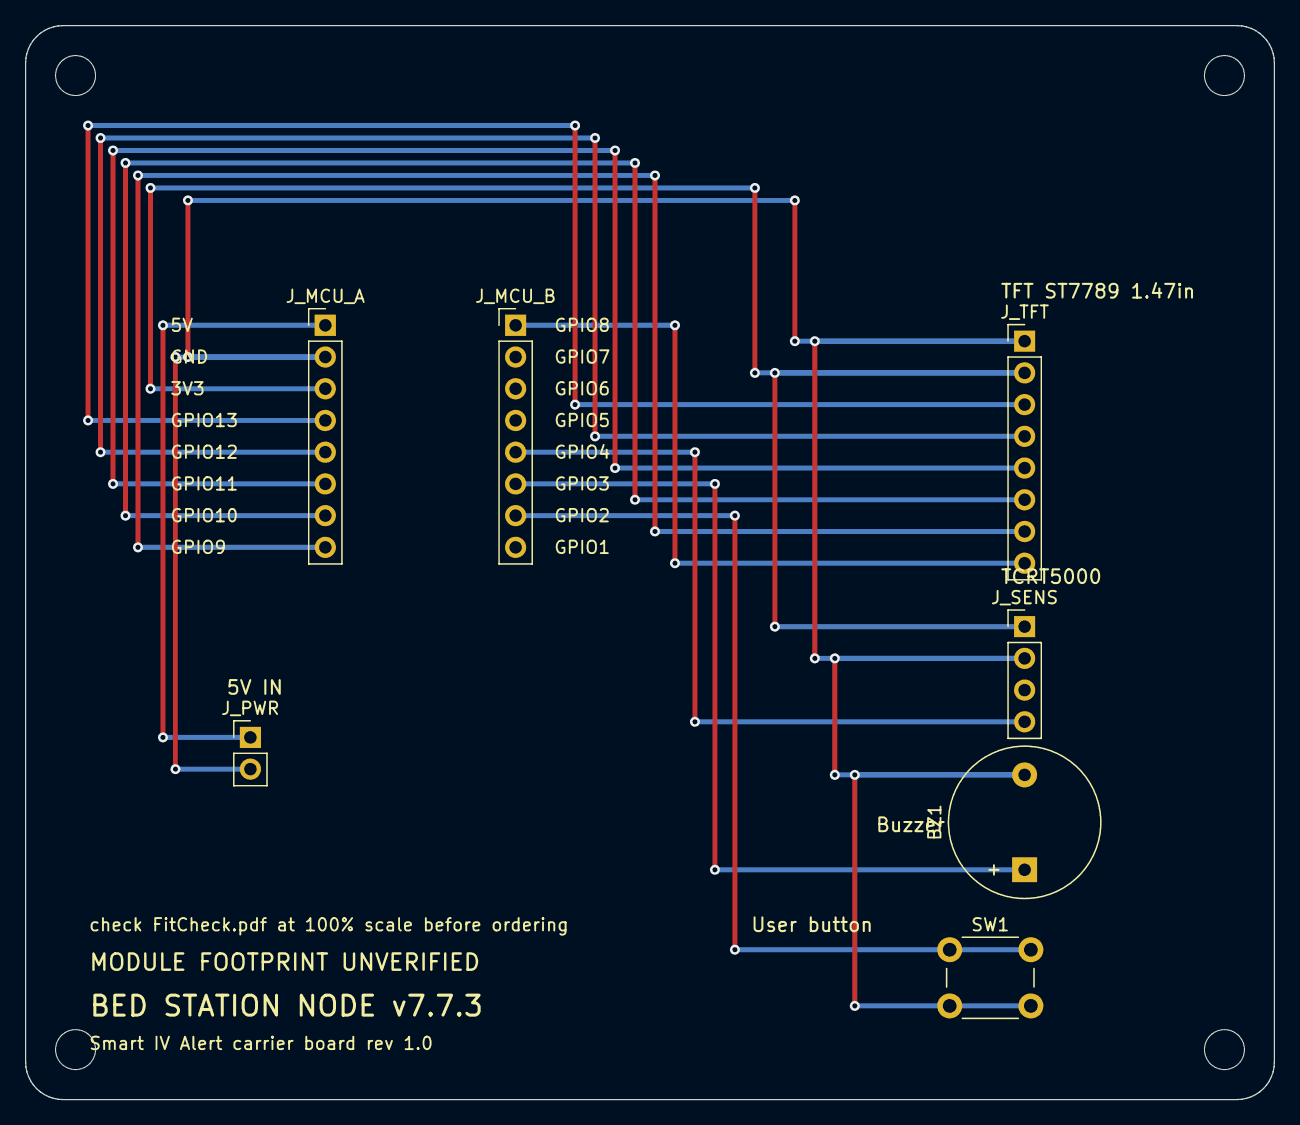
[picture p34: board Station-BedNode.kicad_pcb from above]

Board: 2 copper layers, 100.0 x 86.0 mm, 11 parts (0 on the bottom side), 12 nets.

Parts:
BZ1: Buzzer; Buzzer_12x9.5RM7.6
H1, H2, H3, H4: MountingHole_3.2mm_M3
J_MCU_A: ESP32-S3 row A; PinHeader_1x08_P2.54mm_Vertical
J_MCU_B: ESP32-S3 row B; PinHeader_1x08_P2.54mm_Vertical
J_PWR: 5V IN; PinHeader_1x02_P2.54mm_Vertical
J_SENS: TCRT5000; PinHeader_1x04_P2.54mm_Vertical
J_TFT: TFT ST7789 1.47in; PinHeader_1x08_P2.54mm_Vertical
SW1: User button; SW_PUSH_6mm

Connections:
+3V3: J_MCU_A.3, J_SENS.1, J_TFT.2
+5V: J_MCU_A.1, J_PWR.1
BTN: J_MCU_B.7, SW1.1
BUZZER: BZ1.1, J_MCU_B.6
DROP_AO: J_MCU_B.5, J_SENS.4
GND: BZ1.2, J_MCU_A.2, J_PWR.2, J_SENS.2, J_TFT.1, SW1.2
TFT_BLK: J_MCU_B.1, J_TFT.8
TFT_CS: J_MCU_A.8, J_TFT.7
TFT_DC: J_MCU_A.7, J_TFT.6
TFT_MOSI: J_MCU_A.5, J_TFT.4
TFT_RST: J_MCU_A.6, J_TFT.5
TFT_SCLK: J_MCU_A.4, J_TFT.3

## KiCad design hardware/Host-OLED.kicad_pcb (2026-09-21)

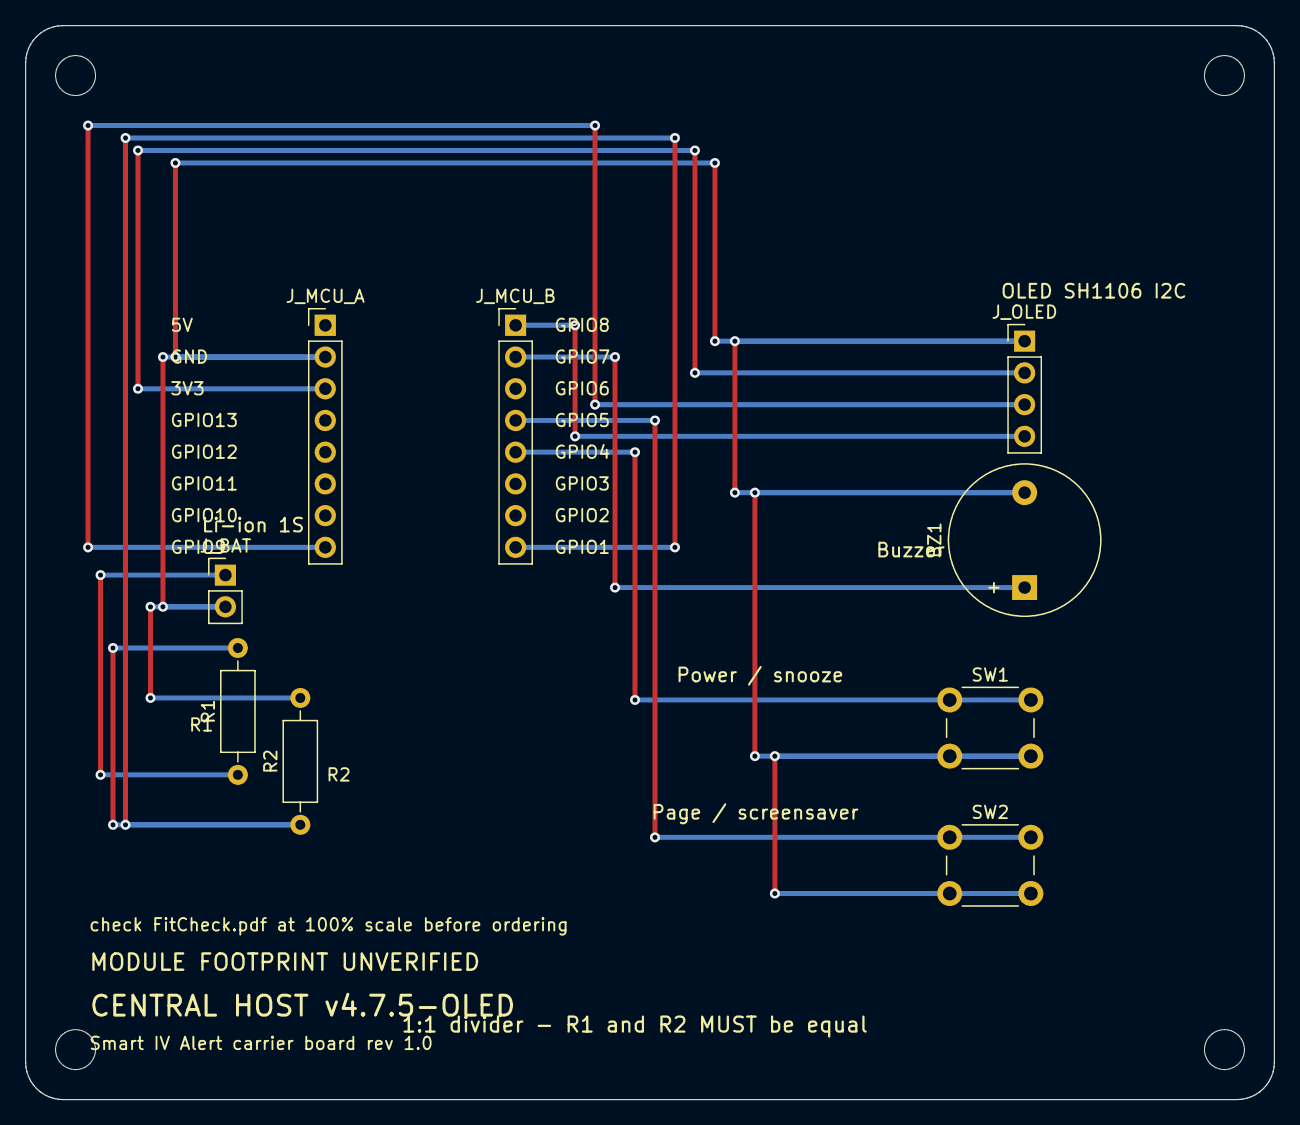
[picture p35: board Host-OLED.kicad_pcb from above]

Board: 2 copper layers, 100.0 x 86.0 mm, 13 parts (0 on the bottom side), 9 nets.

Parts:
BZ1: Buzzer; Buzzer_12x9.5RM7.6
H1, H2, H3, H4: MountingHole_3.2mm_M3
J_BAT: Li-ion 1S; PinHeader_1x02_P2.54mm_Vertical
J_MCU_A: ESP32-S3 row A; PinHeader_1x08_P2.54mm_Vertical
J_MCU_B: ESP32-S3 row B; PinHeader_1x08_P2.54mm_Vertical
J_OLED: OLED SH1106 I2C; PinHeader_1x04_P2.54mm_Vertical
R1, R2: 100k; R_Axial_DIN0207_L6.3mm_D2.5mm_P10.16mm_Horizontal
SW1: Power/snooze; SW_PUSH_6mm
SW2: Page; SW_PUSH_6mm

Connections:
+3V3: J_MCU_A.3, J_OLED.2
BTN_PAGE: J_MCU_B.4, SW2.1
BTN_POWER: J_MCU_B.5, SW1.1
BUZZER: BZ1.1, J_MCU_B.2
GND: BZ1.2, J_BAT.2, J_MCU_A.2, J_OLED.1, R2.2, SW1.2, SW2.2
OLED_SCL: J_MCU_A.8, J_OLED.3
OLED_SDA: J_MCU_B.1, J_OLED.4
VBAT+: J_BAT.1, R1.1
VBAT_SENSE: J_MCU_B.8, R1.2, R2.1

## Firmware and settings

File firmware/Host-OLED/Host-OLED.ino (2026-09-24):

/**
 * @file      Host-OLED.ino
 * @brief     เฟิร์มแวร์เครื่องส่วนกลาง รุ่นจอ OLED รับข้อมูลทุกเตียงและแจ้งเตือนพยาบาล
 * @version   4.8.0-OLED
 * @date      2026-09-23
 * @author    นายกิตติพันธ์ รัตนคร <kittiphun.rut@mcu.ac.th>
 *
 * @par Organization
 * วิทยาลัยพยาบาลบรมราชชนนี แพร่ คณะพยาบาลศาสตร์ สถาบันพระบรมราชชนก
 * หอผู้ป่วยอายุรกรรม โรงพยาบาลสูงเม่น จังหวัดแพร่
 * อาจารย์ที่ปรึกษา ดร.กรรณิการ์ กาศสมบูรณ์
 *
 * @par Hardware
 * ESP32-S3 Dev Module (N16R8) + จอ 1.3" OLED (SH1106 I2C 128x64) + Passive Buzzer
 *
 * @par Description
 * รับข้อมูลจากเครื่องประจำเตียงทุกเตียงผ่าน ESP-NOW ประเมินเหตุที่ต้องแจ้งเตือน
 * แล้วส่งค่าตามแผนการรักษากลับไปให้แต่ละเตียง พร้อมให้บริการหน้าเว็บ Dashboard
 * ไฟล์นี้เก็บตรรกะการรับส่ง การแจ้งเตือน เครือข่าย และ REST API
 * ส่วนที่วาดลงจออยู่ที่ `HostScreen.h` และหน้าเว็บอยู่ที่ `web_dashboard.h`
 *
 * @par Revision History
 * | Version | Date | Change |
 * |---|---|---|
 * | 4.8.0-OLED | 2026-09-23 | เตียงที่หายไประหว่างให้น้ำเกลือมีเสียงเตือนแล้ว เพิ่มสุนัขเฝ้าบ้าน รายงานสาเหตุการรีบูต และปฏิเสธแพ็กเก็ตที่ค่าเป็นไปไม่ได้ |
 * | 4.7.7-OLED | 2026-09-23 | ย้ายโค้ดวาดจอออกไปไว้ที่ `HostScreen.h` ตรรกะไม่เปลี่ยนแม้แต่บรรทัดเดียว |
 * | 4.7.6-OLED | 2026-09-23 | นำการเชื่อมต่อเราเตอร์กลับมาเพื่อลดภาระซีพียู และปรับจังหวะ poll ตามจำนวนผู้ใช้ |
 * | 4.7.5-OLED | 2026-09-12 | แก้บั๊ก `oldPlan` อ่านค่าหลังเขียนทับ และหยดปลอมบนแอนิเมชัน |
 * | 4.7.4-OLED | 2026-09-20 | ตรวจจับเลขเตียงซ้ำ และปรับจอ OLED ให้อ่านง่ายขึ้น |
 * | 4.7.3-OLED | 2026-09-12 | แก้จังหวะส่ง Sync ที่ชนกัน วัดคุณภาพลิงก์ และแอนิเมชันหยด |
 * | 4.7.2-OLED | 2026-09-18 | ปรับหน้าเว็บ Dashboard ตามที่พยาบาลขอ |
 * | 4.7.1-OLED | 2026-09-12 | รองรับ Station หลายสาย และเตือนเมื่อเซนเซอร์ยังไม่จับหยด |
 * | 4.7.0-OLED | 2026-09-16 | ตัดการจัดการ Wi-Fi ออก เหลือโหมด Access Point อย่างเดียว |
 *
 * @warning  ไฟล์วาดจอถูก `#include` ท้ายไฟล์นี้ก่อน `setup()` ห้ามย้ายขึ้นไปบนสุด
 *           เพราะโค้ดในไฟล์นั้นใช้ตัวแปรและฟังก์ชันช่วยที่ประกาศไว้ด้านบน
 *
 * @warning  `struct_message` และ `struct_host_sync` ต้องเหมือนกันทุกไบต์ในทุกเฟิร์มแวร์
 *           ตรวจด้วย `bash tools/protocol-test/run.sh` ก่อน commit ทุกครั้งที่แตะโครงสร้างนี้
 *
 * @warning  ยังไม่ได้ทดสอบบนฮาร์ดแวร์จริง ตรวจด้วยเครื่องมือจำลองบนเครื่อง PC เท่านั้น
 *
 * @par บันทึกการเปลี่ยนแปลงโดยละเอียด
 * เก็บข้อความเดิมไว้ทั้งหมด เพราะเหตุผลเชิงเทคนิคในนั้นหาจากที่อื่นไม่ได้
 *  เปลี่ยนใน V4.7.6-OLED: นำการเชื่อมต่อเราเตอร์กลับมา เพื่อลดภาระซีพียู
 *
 *   ปัญหา: เมื่อมีสมาร์ตโฟนหลายเครื่องเปิดหน้าเว็บพร้อมกัน เครื่องต้องทำหน้าที่
 *   Access Point ให้ทุกเครื่องเอง ทั้งส่ง beacon จัดการการเข้าร่วม และกันบัฟเฟอร์
 *   ไว้ต่อเครื่อง งานเหล่านี้แย่งเวลาจากการรับสัญญาณ ESP-NOW ของเตียง
 *
 *   1) โหมดเครือข่ายใหม่: เกาะเราเตอร์เป็นหลัก ถ้าต่อไม่ได้ค่อยเปิด AP สำรอง
 *      ต่อเราเตอร์สำเร็จ = ปิด AP ทิ้ง ภาระส่วนนี้หายหมด ไม่ใช่ WIFI_AP_STA
 *      ที่เปิดทั้งสองอย่างค้างไว้เหมือน v4.6.0 ซึ่งไม่ได้ลดภาระเลย
 *   2) ต่อไม่ได้ใน 15 วินาที หรือเราเตอร์หลุดเกิน 20 วินาที -> เปิด AP กลับมาเอง
 *      พยาบาลต่อ SSID เดิมได้เหมือนทุกวัน ไม่มีช่วงที่เข้าหน้าเว็บไม่ได้
 *   3) ขณะใช้ AP สำรอง จะลองกลับไปเกาะเราเตอร์ทุก 10 นาที แต่เฉพาะตอนไม่มีใคร
 *      ต่อ AP อยู่ เพราะการสลับโหมดจะตัดการเชื่อมต่อของผู้ใช้
 *   4) ESP-NOW ใช้ช่องของเราเตอร์ได้เลย ไม่ต้องบังคับกลับเป็นช่อง 1
 *      เพราะ Station มี manageChannelHunting() ไล่หาช่องเอง เจอภายใน ~33 วินาที
 *      (v4.6.0 บังคับช่องกลับหลังเกาะเราเตอร์ ซึ่งทำให้ลิงก์เราเตอร์พังทันที)
 *   5) การค้นหาเครือข่ายใช้แบบไม่บล็อก หน้าเว็บถามผลซ้ำจนกว่าจะเสร็จ
 *      (v4.6.0 ใช้ WiFi.scanNetworks() แบบบล็อก ทำให้แพ็กเก็ตจากเตียงหายช่วงสแกน)
 *   6) สั่งปิดโหมดประหยัดพลังงานของวิทยุซ้ำสามจุดรอบการเข้าโหมด STA
 *      เพราะ Arduino core เรียก esp_wifi_set_ps() ทับตอน STA_START ด้วยค่าปริยาย
 *      WIFI_PS_MIN_MODEM ของ ESP32-S3 ซึ่งทำให้ตัวรับหลับและแพ็กเก็ตมาถึงช้าเป็นวินาที
 *   7) หน้าเว็บปรับจังหวะรีเฟรชตามจำนวนผู้ใช้จริง Host วัดอัตราเรียก /api/data
 *      แล้วบอก pollMs กลับไป ยืดได้ถึง 4 วินาทีเมื่อคนเปิดพร้อมกันมาก
 *      และเปลี่ยนจาก setInterval เป็น setTimeout ต่อทอด คำขอจึงไม่ทับถมกันเป็นคิว
 *   8) จอ OLED แสดงที่อยู่ที่ต้องพิมพ์ทั้งบนหน้าพักจอและหน้า LINK DIAGNOSTIC
 *      เพราะที่อยู่เปลี่ยนตามเราเตอร์ ไม่ใช่ 192.168.4.1 คงที่เหมือนเดิม
 *
 *   ตรรกะการวัด การแจ้งเตือน และโครงสร้างแพ็กเก็ต Protocol v3 ไม่เปลี่ยนแม้แต่ไบต์เดียว
 *
 *  เปลี่ยนใน V4.7.2-OLED: ปรับหน้าเว็บ Dashboard ตามที่พยาบาลขอมา
 *   1) สถานะปกติมี "กรอบสีเขียว" รอบการ์ดเตียง มองแวบเดียวรู้ว่าเตียงไหนเรียบร้อย
 *      (เดิมปกติไม่มีกรอบ ทำให้แยกจากเตียงออฟไลน์ด้วยสายตายาก)
 *   2) การเตือนใกล้หมดบอกเป็น "% ของสารน้ำ" แทนตัวเลข mL ที่ตั้งไว้
 *      และเพิ่มบรรทัด "เหลือในกระปุก ... mL" ในการ์ดทุกใบ (เดิมมีแต่ยอดที่ให้ไปแล้ว)
 *   3) เพิ่มแถบแจ้งเตือนรวมบนหน้า Live Monitor บอกว่าเตียงไหนเป็นอะไร
 *      ครอบคลุมทั้ง ไหลช้า / ไหลเร็ว / ไม่ไหล / ให้ครบแล้ว / เซนเซอร์ไม่จับหยด
 *      พร้อมแถบสีส้มแยกต่างหากสำหรับเตียงที่ใกล้หมด (เฝ้าดู ไม่ใช่เหตุวิกฤต)
 *   4) เสียงเตือนบนหน้าเว็บกระตุ้นความสนใจขึ้น — จากเสียงไซน์ 880 Hz ครั้งเดียว
 *      เป็นชุด 4 พัลส์สลับสองความถี่แบบรถพยาบาล ใช้คลื่นสี่เหลี่ยมที่มีฮาร์มอนิกมาก
 *      จึงแทรกผ่านเสียงรบกวนในหอผู้ป่วยได้ดีกว่า และปล่อยซ้ำทุก 2 วินาทีจนกว่าเหตุจะหาย
 *   5) ป้ายเวอร์ชันบนหัวหน้าเว็บอ่านจาก APP_VERSION จริง (เดิมค้างที่ v4.6.0)
 *
 *   ตรรกะการวัด การแจ้งเตือน และโปรโตคอล ESP-NOW ไม่เปลี่ยนแม้แต่ไบต์เดียว
 *
 *  เปลี่ยนใน V4.7.1-OLED: รองรับเครื่องประจำเตียงรุ่นใหม่ (v7.5.1 และ v7.7.0)
 *
 *   โครงสร้างแพ็กเก็ต ESP-NOW ของ Station v7.5.1 และ v7.7.0 เหมือน v7.4.x ทุกไบต์
 *   (struct_message 23 ไบต์ / struct_host_sync 20 ไบต์) และสูตรตัดสินสายพับก็สูตรเดียวกัน
 *   จึงใช้งานร่วมกันได้อยู่แล้วโดยไม่ต้องแก้โปรโตคอล — ตรวจซ้ำได้ด้วย tools/protocol-test
 *
 *   แต่มีช่องโหว่ที่เห็นชัดขึ้นเมื่อใช้กับ v7.7.0 ซึ่งมีสถานะ "เซนเซอร์ยังจับหยดไม่ได้"
 *   ในตัวเครื่องเอง ขณะที่ Host เดิมไม่มีสถานะนี้เลย:
 *
 *    เตียงที่ออนไลน์อยู่ กำลังนับอยู่ แต่เซนเซอร์ไม่เคยจับหยดได้สักหยดเดียว
 *    (วางเซนเซอร์ผิดตำแหน่ง สายหลุด เลนส์สกปรก) Host เดิมจะขึ้นว่า "ปกติ" ตลอดไป
 *    เพราะเงื่อนไขสายพับกำหนดว่าต้องเคยมีหยดมาก่อน (totalDrops == 0 -> ไม่เข้าเงื่อนไข)
 *    นี่คือความล้มเหลวแบบเงียบ ซึ่งอันตรายกว่าการแจ้งเตือนผิด เพราะพยาบาลเข้าใจว่า
 *    ระบบกำลังเฝ้าอยู่ ทั้งที่ไม่ได้นับอะไรเลย
 *
 *   สิ่งที่เพิ่ม
 *    - รหัสเตือนใหม่ ALERT_NO_SIGNAL (6) = "เซนเซอร์ยังไม่จับหยด" แยกจากสายพับชัดเจน
 *      เพราะสองอย่างนี้ให้พยาบาลไปดูคนละจุด (สายพับ = ดูสายน้ำเกลือ, ไม่มีสัญญาณ = ดูเซนเซอร์)
 *    - เงื่อนไข: ออนไลน์ + กำลังนับ + ยังไม่เคยมีหยดเลย + ต่อเนื่องเกิน NO_SIGNAL_MS
 *    - ถือเป็นเหตุวิกฤต จึงมีเสียงเตือนที่ Host และขึ้นบนจอ OLED / หน้าเว็บ / ไฟล์ CSV
 *    - **ไม่ส่งรหัสนี้ออกไปที่ Station** เพื่อความเข้ากันได้ย้อนหลังอย่างสมบูรณ์
 *      (Station รุ่นเก่าไม่รู้จักรหัส 6) ตอนส่ง Sync จะแปลงเป็น ALERT_NONE เสมอ
 *      เครื่องที่เตียงรุ่น v7.7.0 มีสถานะ CHECK SENSOR ของตัวเองอยู่แล้ว
 *
 *  เปลี่ยนใน V4.7.0: ตัดระบบจัดการ Wi-Fi (Router/อินเทอร์เน็ต) ออกทั้งหมด
 *   - Host เกาะเราเตอร์เป็นหลัก (WIFI_STA) ถ้าต่อไม่ได้เปิด Access Point สำรอง (WIFI_AP)
 *     -> ไม่มีการสแกนช่อง/รีคอนเนกต์มาแย่งเวลาคลื่นวิทยุ ESP-NOW และ Web Server อีก
 *   - รองรับสมาร์ตโฟน/แท็บเล็ตพร้อมกันได้ถึง AP_MAX_CLIENTS เครื่อง (เดิมค่าปริยาย 4
 *     และในโหมด AP+STA เหลือใช้งานจริงเพียง 2-3 เครื่อง)
 *   - ปิดโหมดประหยัดพลังงานของ Wi-Fi (WIFI_PS_NONE) ให้ตอบสนองหลายเครื่องพร้อมกันได้นิ่ง
 *   - ESP-NOW ส่งผ่านอินเทอร์เฟซที่ใช้อยู่จริง (WIFI_IF_STA หรือ WIFI_IF_AP)
 *   - ตั้งเวลาจากนาฬิกาของเครื่องที่เปิดหน้าเว็บโดยอัตโนมัติ (แทน NTP) และสำรองเวลาไว้ใน NVS
 *     ทุก 10 นาที เพื่อให้เวลาไม่หายเมื่อไฟดับ (แสดงเป็น "เวลาโดยประมาณ" จนกว่าจะซิงก์ใหม่)
 *   - หน้าเว็บ: เอาเมนูจัดการ Wi-Fi ออก เหลือหน้าต่างแสดงข้อมูลจุดเชื่อมต่อแบบอ่านอย่างเดียว
 *     และหยุด Poll ข้อมูลเมื่อสลับแท็บไปทำอย่างอื่น (ลดภาระเมื่อมีผู้ใช้หลายเครื่อง)
 *
 *  เพิ่มใน V4.6.0: แจ้งเตือนใกล้หมด (เตรียมถุงใหม่)
 *   - ตั้ง % ต่อเตียงจากหน้าเว็บ (50-95%, ค่าเริ่มต้น 80%) เก็บถาวรใน NVS
 *   - Host เสียงเตือนเบา 3 ครั้ง ซ้ำทุก 5 นาทีจนกว่าจะรับทราบ (ที่เตียง / ปุ่ม POWER / หน้าเว็บ)
 *   - รับทราบแล้วซิงก์ไปทุกจุด และล้างเมื่อกด "เริ่มถุงใหม่" หรือแก้ปริมาตร/เปอร์เซ็นต์
 *
 *  สรุปการแก้ไขจาก V4.4.1 (โค้ดภายในระบุ 6.3.2)
 *   1) แก้จุดที่คอมไพล์ไม่ผ่าน (ฟิลด์ใน StationData / ชื่อฟังก์ชัน-ตัวแปรใน loop)
 *   2) โครงสร้างแพ็กเก็ต ESP-NOW ตรงกับ Station ทุกไบต์ (มี static_assert ตรวจขนาด)
 *   3) Station ส่งอัตราไหลที่คำนวณจากช่วงห่างระหว่างหยด + เวลาตั้งแต่หยดล่าสุด
 *      -> เลิกคำนวณ rate จากหน้าต่าง 2 วินาทีที่ทำให้แจ้งเตือนสายพับผิด
 *   4) Host เป็นผู้ตัดสินรหัสเตือนจุดเดียว เรียก evaluateClinicalAlerts() ทุก 1 วินาที
 *   5) ส่ง Sync ทุก 1 วินาที (เดิม 10 วินาที ขณะที่ Station ตัดสินว่าหลุดที่ 5 วินาที)
 *   6) เพิ่ม API /api/stations/config และ /api/stations/reset
 *      ค่า Target Rate / Plan Volume / Drop Factor / ชื่อผู้ป่วย เก็บที่ Host (NVS)
 *   7) Drop factor ใช้ค่าของแต่ละเตียง (10/15/20/60) แทนค่าคงที่ 20
 *   8) นับหยดรายนาทีจากผลต่าง totalDrops -> แพ็กเก็ตหายไม่ทำให้ข้อมูลหาย
 *   9) SoftAP ล็อก Channel 1
 *  10) Deep sleep ใช้ ext0 wakeup (esp_deep_sleep_enable_gpio_wakeup ไม่รองรับ ESP32-S3)
 *  11) ปุ่ม POWER กดสั้นขณะมีเสียงเตือน = พักเสียง 2 นาที (Snooze)
 */

#include <WiFi.h>
#include <esp_now.h>
#include <esp_wifi.h>
#include <WebServer.h>
#include <Preferences.h>
#include <ESPmDNS.h>
#include <U8g2lib.h>
#include <Wire.h>
#include <time.h>
#include <sys/time.h>
#include <driver/rtc_io.h>
#include <esp_task_wdt.h>          // [4.8.0-OLED] เพิ่ม: สุนัขเฝ้าบ้าน กันเครื่องค้างเงียบ
#include <esp_system.h>            // [4.8.0-OLED] เพิ่ม: อ่านสาเหตุการรีบูตครั้งล่าสุด

// ----------------------------------------------------------------------------
// สุนัขเฝ้าบ้านและสาเหตุการรีบูต ([4.8.0-OLED] เพิ่มทั้งหมด)
//
// เครื่องนี้ทำหน้าที่เตือนภัย การค้างแบบเงียบจึงอันตรายกว่าการรีบูต เพราะจอยัง
// ค้างภาพเดิมไว้ พยาบาลจึงเข้าใจว่าระบบยังเฝ้าอยู่ ทั้งที่หยุดไปแล้ว
// ตั้งไว้ 8 วินาที ซึ่งยาวกว่ารอบ loop() ปกติหลายเท่า จึงไม่รีบูตเพราะงานหนักชั่วคราว
// ----------------------------------------------------------------------------
#define LOOP_WDT_TIMEOUT_S      8

esp_reset_reason_t bootResetReason = ESP_RST_UNKNOWN;


#define APP_VERSION         "4.8.0-OLED"
#define DEV_NAME            "กิตติพันธ์ รัตนคร"
#define DEV_ROLE            "นักวิชาการคอมพิวเตอร์"
#define DEV_INSTITUTION     "มหาวิทยาลัยมหาจุฬาลงกรณราชวิทยาลัย วิทยาเขตแพร่"

// ----------------------------------------------------------------------------
// กำหนดขาเชื่อมต่อฮาร์ดแวร์ฝั่ง Host
// ----------------------------------------------------------------------------
#define HOST_BAT_ADC_PIN    1   // ขาอ่านแบตเตอรี่ Host
#define POWER_BTN_PIN       4   // ปุ่มเปิด-ปิดหน้าจอ / พักเสียงเตือน (Snooze) — ต้องเป็น RTC GPIO (0-21)
#define PAGE_BTN_PIN        5   // ปุ่มเปลี่ยนหน้าจอ / ดับเบิ้ลคลิกเรียก Screensaver
#define BUZZER_PIN          7   // ขาต่อลำโพง Passive Buzzer
#define OLED_SDA_PIN        8   // ขา I2C SDA จอ OLED
#define OLED_SCL_PIN        9   // ขา I2C SCL จอ OLED

// ----------------------------------------------------------------------------
// ค่าคงที่ของระบบสื่อสารและการแจ้งเตือน (ต้องตรงกับ Station)
// ----------------------------------------------------------------------------
#define ESPNOW_CHANNEL          1        // ช่อง SoftAP / ESP-NOW เริ่มต้น
#define SYNC_INTERVAL_MS        1000     // แต่ละเตียงได้รับ Sync ครบ 1 ใบทุก 1 วินาที
#define SYNC_SLOT_MIN_MS        60       // ช่องเวลาต่ำสุดระหว่างแพ็กเก็ต Sync สองใบ
#define ONLINE_TIMEOUT_MS       8000     // ไม่ได้รับข้อมูลเกิน 8 วินาที = OFFLINE
#define LOST_LINK_GRACE_MS      30000    // [4.8.0-OLED] เพิ่ม: เงียบต่อจาก OFFLINE อีกเท่านี้จึงถือว่าขาดการติดต่อจริง
#define MAX_PLAUSIBLE_RATE_HR   3000.0f  // [4.8.0-OLED] เพิ่ม: ชุดให้สารน้ำมาตรฐานไหลได้ไม่ถึงเท่านี้
#define MAX_PLAUSIBLE_BATT_V    6.0f     // [4.8.0-OLED] เพิ่ม: แบตลิเธียมเซลล์เดียว ไม่มีทางถึง 6 โวลต์
                                         // Station ส่งวินาทีละใบ ค่านี้จึงยอมให้หายติดกัน 8 ใบ
                                         // (เดิม 5 วินาที = 5 ใบ ซึ่งน้อยเกินไปเมื่อมีหลายเตียง)
#define LINK_WINDOW_MS          10000UL  // หน้าต่างวัดคุณภาพลิงก์ (คาดหวัง 10 ใบ)
#define LINK_WEAK_PCT           60       // ต่ำกว่านี้ = ลิงก์อ่อน เตือนก่อนหลุดจริง
#define ID_CONFLICT_WINDOW_MS   30000UL  // ช่วงเวลาที่นับการสลับ MAC ของเลขเตียงเดียวกัน
#define ID_CONFLICT_MIN_FLIPS   4        // สลับเกินเท่านี้ใน 1 ช่วง = มีบอร์ดตั้งเลขซ้ำกันแน่
#define HEARD_REMEMBER_MS       60000UL  // จำไว้ว่าเคยได้ยินเลขเตียงนี้นานเท่าใด
#define OLED_ANIM_INTERVAL_MS   90       // ~11 เฟรม/วินาที ขณะมีหยดให้แสดง
#define OLED_IDLE_INTERVAL_MS   400      // ไม่มีหยดให้แสดง
#define OLED_I2C_HZ             400000   // 400 kHz = ตามสเปก SH1106 (เดิมใช้ค่าปริยาย 100 kHz)
#define DROP_FALL_MS            240      // เวลาที่หยดหนึ่งหยดใช้ตกในแอนิเมชัน
#define MIN_OCCLUSION_MS        8000     // เวลาต่ำสุดที่ไม่มีหยดก่อนถือว่าหยุดไหล
#define NO_SIGNAL_MS            90000UL  // ติดต่อกันได้นานเท่านี้แต่ไม่เคยมีหยดเลย
                                         // = เซนเซอร์ยังจับหยดไม่ได้ (ไม่ใช่สายพับ)
                                         // 90 วินาที เผื่อเวลาพยาบาลจัดตำแหน่งเซนเซอร์เสร็จ
#define MAX_OCCLUSION_MS        300000   // เพดานเวลาตัดสินหยุดไหล (อัตราต่ำมาก)
#define RATE_DEVIATION_HOLD_MS  20000    // เร็ว/ช้าเกินต่อเนื่อง 20 วินาทีจึงเตือน
#define SNOOZE_MS               120000   // พักเสียง 2 นาที
#define NEAR_END_REMIND_MS      300000   // เตือนใกล้หมดซ้ำทุก 5 นาทีจนกว่าจะรับทราบ
#define DEFAULT_NEAR_END_PCT    80       // เตือนเมื่อให้ไปแล้ว 80% ของปริมาตรตามแผน
#define AP_MAX_CLIENTS          8        // จำนวนสมาร์ตโฟน/แท็บเล็ตที่ต่อพร้อมกันได้ (สูงสุด 10)
#define TIME_BACKUP_INTERVAL_MS 600000   // สำรองเวลาปัจจุบันลง NVS ทุก 10 นาที

// ---- โหมดเครือข่าย: เกาะเราเตอร์เป็นหลัก ถ้าต่อไม่ได้ค่อยเปิด AP สำรอง ----
// เหตุผล: เมื่อสมาร์ตโฟนต่อผ่านเราเตอร์ Host ไม่ต้องทำหน้าที่ Access Point
// จึงไม่มีภาระ beacon / การจัดการ client / บัฟเฟอร์ต่อเครื่อง
#define STA_CONNECT_TIMEOUT_MS  15000    // รอเกาะเราเตอร์นานสุด 15 วินาที
#define STA_LOST_GRACE_MS       20000    // หลุดจากเราเตอร์เกินเท่านี้ -> เปิด AP สำรอง
#define STA_RETRY_INTERVAL_MS   600000   // ขณะใช้ AP สำรอง ลองกลับไปเกาะเราเตอร์ทุก 10 นาที
                                         // (ลองเฉพาะตอนไม่มีใครต่อ AP อยู่ จะได้ไม่กวนผู้ใช้)

// ---- ปรับจังหวะ poll ของหน้าเว็บตามจำนวนผู้ใช้จริง ----
#define API_RATE_WINDOW_MS      5000     // หน้าต่างนับอัตราการเรียก /api/data
#define POLL_MS_MIN             1000     // ผู้ใช้น้อย = รีเฟรชทุก 1 วินาทีเหมือนเดิม
#define POLL_MS_MAX             4000     // ผู้ใช้มาก = ยืดถึง 4 วินาที กันซีพียูตัน

// รหัสแจ้งเตือน (ใช้ร่วมกันทั้ง Host / Station / Web)
#define ALERT_NONE        0
#define ALERT_TOO_FAST    1
#define ALERT_TOO_SLOW    2
#define ALERT_NEAR_END    3   // ให้ไปแล้วถึง % ที่ตั้ง (เตือนเบา ไม่ใช่เหตุวิกฤต)
#define ALERT_COMPLETE    4   // ให้ครบตามแผนแล้ว
#define ALERT_OCCLUSION   5   // สายพับ / หยุดไหล
#define ALERT_NO_SIGNAL   6   // เซนเซอร์ยังไม่จับหยดเลย (คนละเรื่องกับสายพับ)
#define ALERT_LOST_LINK   7   // [4.8.0-OLED] เพิ่ม: เตียงที่กำลังให้น้ำเกลือหายไปจากอากาศ (ใช้ฝั่ง Host เท่านั้น)
                              // ใช้ภายใน Host เท่านั้น ไม่ส่งออกไปที่ Station

// โหมดภาพของกระเปาะหยดบนจอ Host — ให้ตรงกับที่จอ Station แสดงในหน้า 1 IV BAG
// (ประกาศไว้ตอนต้นไฟล์ เพราะ Arduino แทรก prototype ของฟังก์ชันไว้ก่อนส่วนแสดงผล)
enum DripMode : uint8_t {
  DRIP_FLOW = 0,     // กำลังไหล — มีหยดวิ่งลงมา
  DRIP_PAUSED = 1,   // พยาบาลสั่งหยุดนับ — สัญลักษณ์ Pause เหมือนจอ Station
  DRIP_ALERT = 2,    // สายพับ / เซนเซอร์ยังไม่จับหยด — เครื่องหมายตกใจ
  DRIP_OFFLINE = 3   // ติดต่อเตียงไม่ได้ — กากบาท
};

U8G2_SH1106_128X64_NONAME_F_HW_I2C u8g2(U8G2_R0, /* reset=*/ U8X8_PIN_NONE);

const char *default_ap_ssid = "ESP32_Liquid_Monitor";
const char *default_ap_pass = "12345678";
const char *web_username    = "admin";
const char *web_password    = "password123";

// เขตเวลาไทย (ICT UTC+7) — ตั้งค่าในตัวเครื่อง ไม่พึ่ง NTP อีกต่อไป
const char* TZ_THAILAND     = "ICT-7";

#define MAX_SUPPORTED_STATIONS 8
#define MAX_LOGS 60

WebServer server(80);
Preferences preferences;

// ---- สถานะเครือข่าย ----
enum NetMode : uint8_t { NET_MODE_AP = 0, NET_MODE_STA = 1 };
NetMode  netMode          = NET_MODE_AP;   // โหมดที่ใช้อยู่จริงในขณะนี้
String   staSsid          = "";
String   staPass          = "";
bool     staConfigured    = false;         // มีรหัสเราเตอร์บันทึกไว้หรือไม่
bool     staConnecting    = false;         // กำลังรอเกาะเราเตอร์อยู่
uint32_t staAttemptStart  = 0;
uint32_t staLostSince     = 0;             // เวลาที่เริ่มหลุดจากเราเตอร์ (0 = ไม่ได้หลุด)
uint32_t lastStaRetry     = 0;
int8_t   lastStaRssi      = 0;

// ---- ตัวนับอัตราการเรียก /api/data เพื่อปรับจังหวะ poll ให้หน้าเว็บ ----
uint16_t apiDataHits       = 0;
uint32_t apiRateWindowAt   = 0;
uint16_t currentPollMs     = POLL_MS_MIN;
portMUX_TYPE dataMux = portMUX_INITIALIZER_UNLOCKED;

uint8_t activeStationCount  = 5;
uint8_t currentOledPage     = 0;
bool oledDisplaySleeping    = false;
bool oledScreensaverActive  = false;
bool isPowerOffProgressActive = false;
unsigned long lastUserActivityTime = 0;
bool isTimeSynced           = false;   // ตั้งเวลาจากเครื่องผู้ใช้ผ่านหน้าเว็บแล้ว
bool isTimeApprox           = false;   // กู้เวลาจากที่สำรองไว้ตอนบูต (ยังไม่ซิงก์ใหม่)
unsigned long lastTimeBackup = 0;

uint8_t broadcastAddress[] = {0xFF, 0xFF, 0xFF, 0xFF, 0xFF, 0xFF};

// ----------------------------------------------------------------------------
// โครงสร้างข้อมูลรับ-ส่ง ESP-NOW (Protocol v2) — ต้องเหมือนกับ Station ทุกไบต์
// ----------------------------------------------------------------------------
typedef struct __attribute__((packed)) struct_message {
  uint8_t  stationId;
  uint8_t  isRunning;
  uint32_t totalDrops;
  uint32_t periodDrops;
  float    flowRateHr;       // อัตราไหลที่ Station คำนวณจากช่วงห่างระหว่างหยด (mL/h)
  uint32_t msSinceLastDrop;  // มิลลิวินาทีนับจากหยดล่าสุด (0 = ยังไม่มีหยด)
  float    batteryVolts;     // 0 = ไม่มีวงจรวัดแบตเตอรี่
  uint8_t  flags;            // bit0 = พยาบาลกดรับทราบเตือนใกล้หมดที่เตียง
} struct_message;            // 23 bytes

typedef struct __attribute__((packed)) struct_host_sync {
  uint32_t epochTime;
  uint8_t  isSynced;
  uint8_t  stationId;
  float    targetRateHr;
  float    totalPlanMl;
  uint8_t  alertCode;
  uint8_t  dropFactor;
  uint8_t  resetSeq;         // เปลี่ยนค่าเมื่อกด "เริ่มถุงใหม่" -> Station รีเซ็ตตัวนับ
  uint8_t  hostChannel;
  uint8_t  nearEndPct;       // % ของปริมาตรตามแผนที่เริ่มเตือนใกล้หมด
  uint8_t  flags;            // bit0 = รับทราบเตือนใกล้หมดแล้ว
} struct_host_sync;          // 20 bytes

static_assert(sizeof(struct_message) == 23, "struct_message must be 23 bytes (match Station)");
static_assert(sizeof(struct_host_sync) == 20, "struct_host_sync must be 20 bytes (match Station)");
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
void loop() {
  feedWatchdog();   // [4.8.0-OLED] เพิ่ม: บอกสุนัขเฝ้าบ้านว่ายังเดินอยู่
  server.handleClient();

  checkSmartphonePowerButton();
  checkPageButton();
  handleBuzzerAlarm();

  unsigned long currentMillis = millis();

  // สำรองเวลาลง NVS เป็นระยะ เพื่อให้เวลายังใกล้เคียงเดิมหลังไฟดับ
  if (currentMillis - lastTimeBackup >= TIME_BACKUP_INTERVAL_MS) {
    lastTimeBackup = currentMillis;
    backupClockToNvs();
  }

  // ---- ดูแลการเชื่อมต่อเครือข่าย (ไม่บล็อก) ----
  serviceWifi(currentMillis);

  // ---- ประเมินเตือนทุก 1 วินาที (การส่ง Sync แยกไปอยู่ที่ตัวจัดคิวด้านล่าง) ----
  if (currentMillis - lastSyncBroadcastTime >= SYNC_INTERVAL_MS) {
    lastSyncBroadcastTime = currentMillis;
    evaluateClinicalAlerts();
  }

  // ---- ส่ง Sync ทีละใบแบบเฉลี่ยช่องเวลา + วัดคุณภาพลิงก์ ----
  serviceSyncScheduler();
  serviceLinkQuality();

  // ---- อัปเดตค่าที่คำนวณได้ทุก 2 วินาที ----
  if (currentMillis - lastCalcTime >= 2000) {
    hostBatteryVolts = readHostBattery();
    hostBatteryPct = calculateBatteryPct(hostBatteryVolts);

    portENTER_CRITICAL(&dataMux);
    for (int i = 0; i < MAX_SUPPORTED_STATIONS; i++) {
      stations[i].totalVolumeMl = (float)stations[i].totalDrops / (float)safeDropFactor(stations[i].cfg.dropFactor);
      if (!stations[i].isRunning || !isStationOnline(i)) {
        stations[i].flowRate_ml_hr = 0.0;
      }
    }
    portEXIT_CRITICAL(&dataMux);
    lastCalcTime = currentMillis;
  }

  // รีเฟรชถี่เฉพาะตอนที่มีหยดให้แสดงจริง ๆ เพื่อไม่ให้เปลือง I2C และเวลาในลูปโดยเปล่าประโยชน์
  unsigned long oledRefreshInterval;
  if (oledDisplaySleeping || oledScreensaverActive) oledRefreshInterval = 1000;
  else if (anyBedDripping())                        oledRefreshInterval = OLED_ANIM_INTERVAL_MS;
  else                                              oledRefreshInterval = OLED_IDLE_INTERVAL_MS;
  if (currentMillis - lastOledUpdateTime >= oledRefreshInterval) {
    updateHostOLED();
    lastOledUpdateTime = currentMillis;
  }

  // ---- บันทึก Log รายนาที ----
  if (currentMillis - lastMinuteLogTime >= 60000) {
    globalMinuteCounter++;
    String currentTimestamp = getFormattedDateTime();

    for (int i = 0; i < activeStationCount; i++) {
      StationData &s = stations[i];

      portENTER_CRITICAL(&dataMux);
      uint32_t minuteDrops = s.dropsInCurrentMinute;
      s.dropsInCurrentMinute = 0;
      portEXIT_CRITICAL(&dataMux);

      uint8_t df = safeDropFactor(s.cfg.dropFactor);
      LogEntry entry;
      entry.minuteIndex = globalMinuteCounter;
      snprintf(entry.timeStr, sizeof(entry.timeStr), "%s", currentTimestamp.c_str());
      entry.drops = (minuteDrops > 65535) ? 65535 : (uint16_t)minuteDrops;
      entry.volume = s.totalVolumeMl;
      entry.rateHr = ((float)minuteDrops / (float)df) * 60.0f;   // mL/h จากหยดจริงใน 1 นาที
      entry.targetRate = s.cfg.targetRateHr;
      entry.alertCode = s.alertCode;
      entry.rssi = isStationOnline(i) ? s.rssi : 0;
      entry.battery = s.batteryVolts;

      if (s.logCount < MAX_LOGS) {
        s.logs[s.logCount++] = entry;
      } else {
        memmove(&s.logs[0], &s.logs[1], sizeof(LogEntry) * (MAX_LOGS - 1));
        s.logs[MAX_LOGS - 1] = entry;
      }
    }
    lastMinuteLogTime += 60000;
  }
}

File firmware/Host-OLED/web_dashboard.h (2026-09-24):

/**
 * @file      web_dashboard.h
 * @brief     หน้าเว็บ Dashboard ของเครื่องส่วนกลาง รุ่นจอ OLED
 * @version   4.8.0
 * @date      2026-09-23
 * @author    นายกิตติพันธ์ รัตนคร <kittiphun.rut@mcu.ac.th>
 *
 * @par Organization
 * วิทยาลัยพยาบาลบรมราชชนนี แพร่ คณะพยาบาลศาสตร์ สถาบันพระบรมราชชนก
 * หอผู้ป่วยอายุรกรรม โรงพยาบาลสูงเม่น จังหวัดแพร่
 * อาจารย์ที่ปรึกษา ดร.กรรณิการ์ กาศสมบูรณ์
 *
 * @par Description
 * หน้าเว็บทั้งหน้าเก็บเป็นสตริงเดียวใน PROGMEM แล้วส่งให้เบราว์เซอร์
 * ข้อความบนหน้าเว็บเป็นภาษาไทย ต่างจากข้อความบนจอที่ต้องเป็น ASCII
 *
 * @par Revision History
 * | Version | Date | Change |
 * |---|---|---|
 * | 4.8.0 | 2026-09-23 | หน้าเว็บขึ้นแดงเป็นเหตุวิกฤตเมื่อเตียงที่กำลังให้น้ำเกลือหายไปจากอากาศ |
 * | 4.7.6 | 2026-09-23 | เพิ่มหน้าตั้งค่าเราเตอร์ และปรับจังหวะรีเฟรชตามจำนวนผู้ใช้ที่เปิดพร้อมกัน |
 * | 4.7.2 | 2026-09-18 | ปรับการ์ดเตียง แถบแจ้งเตือนรวม และเสียงเตือนตามที่พยาบาลขอ |
 *
 * @note     ไฟล์นี้ค้างอยู่ที่ 4.7.6 ขณะที่สเก็ตช์เป็น 4.7.7 เพราะรุ่น 4.7.7 แยกแต่โค้ดวาดจอ
 *           ไม่ได้แตะหน้าเว็บเลย การไล่ขยับเลขทุกไฟล์ให้เท่ากันจะทำให้ตารางโกหก
 *
 * @par บันทึกการเปลี่ยนแปลงโดยละเอียด
 * เก็บข้อความเดิมไว้ทั้งหมด เพราะเหตุผลเชิงเทคนิคในนั้นหาจากที่อื่นไม่ได้
 *  หน้าเว็บ Dashboard ของระบบ Smart IV Alert (Central Host)
 *  แยกออกมาจากไฟล์ .ino หลัก เพื่อให้ส่วนเฟิร์มแวร์ (การวัด การแจ้งเตือน ESP-NOW
 *  และการแสดงผลบนจอ) อ่านและแก้ไขได้ง่ายขึ้น — ไฟล์นี้เก็บเฉพาะ HTML/CSS/JavaScript
 *  ของหน้าเว็บที่ส่งให้เบราว์เซอร์เท่านั้น ไม่มีตรรกะของเครื่อง
 *
 *  วิธีแก้ไข
 *   - แก้หน้าตา/ข้อความของหน้าเว็บ ให้แก้ในไฟล์นี้ไฟล์เดียว
 *   - ข้อความทั้งก้อนอยู่ใน raw string R"rawliteral( ... )rawliteral"
 *     จึงใส่เครื่องหมาย " ได้ตามปกติ แต่ห้ามมีข้อความ )rawliteral" อยู่ข้างใน
 *   - ตัวแปรชื่อ PAGE_INDEX ถูกส่งออกด้วย server.send_P() ในไฟล์ .ino
 *   - ไฟล์นี้ต้องอยู่ในโฟลเดอร์เดียวกับไฟล์ .ino (Arduino IDE จะคอมไพล์ให้เอง)
 *
 *  ขนาดโดยประมาณ 90 KB เก็บใน Flash (PROGMEM) ไม่กิน RAM ระหว่างทำงาน
 */

#pragma once

#include <Arduino.h>

const char PAGE_INDEX[] PROGMEM = R"rawliteral(
<!DOCTYPE html>
<html lang="th">
<head>
  <meta charset="UTF-8">
  <meta name="viewport" content="width=device-width, initial-scale=1.0">
  <title>Smart IV Alert System v4.6.0</title>
  <style>
    :root {
      --primary: #0072ff;
      --primary-gradient: linear-gradient(135deg, #0072ff 0%, #00c6ff 100%);
      --bg-color: #f0f4f9;
      --card-bg: #ffffff;
      --text-main: #2d3748;
      --text-muted: #718096;
      --border-color: #e2e8f0;
      --green-bg: #e6fffa;
      --green-text: #234e52;
      --alarm-red: #fff5f5;
    }
    * { box-sizing: border-box; margin: 0; padding: 0; font-family: -apple-system, BlinkMacSystemFont, "Segoe UI", Roboto, "Sarabun", sans-serif; }
    body { background-color: var(--bg-color); color: var(--text-main); padding-bottom: 35px; }

    .header {
      background: var(--primary-gradient);
      color: white;
      padding: 16px 22px;
      box-shadow: 0 4px 12px rgba(0, 114, 255, 0.25);
      display: flex;
      justify-content: space-between;
      align-items: center;
      flex-wrap: wrap;
      gap: 10px;
    }
    .header-title { font-size: 20px; font-weight: 800; display: flex; align-items: center; }
    .header-badge { font-size: 12px; background: rgba(255,255,255,0.25); padding: 3px 9px; border-radius: 6px; margin-left: 8px; }
    .header-subtitle { font-size: 13.5px; opacity: 0.9; margin-top: 3px; display:flex; gap:12px; align-items:center; }
    .host-bat-badge {
      background: rgba(0,0,0,0.2);
      border: 1px solid rgba(255,255,255,0.3);
      padding: 5px 12px;
      border-radius: 8px;
      font-size: 13.5px;
      font-weight: 700;
      display: flex;
      align-items: center;
      gap: 4px;
    }
    .wifi-btn {
      background: rgba(255,255,255,0.25);
      border: 1px solid rgba(255,255,255,0.4);
      color: white;
      padding: 9px 14px;
      border-radius: 10px;
      cursor: pointer;
      font-size: 14.5px;
      font-weight: 600;
    }

    .main-nav {
      background: #ffffff;
      display: flex;
      justify-content: center;
      gap: 10px;
      padding: 12px 16px;
      border-bottom: 1px solid var(--border-color);
      box-shadow: 0 2px 5px rgba(0,0,0,0.02);
      position: sticky;
      top: 0;
      z-index: 100;
      flex-wrap: wrap;
    }
    .nav-btn {
      padding: 10px 18px;
      border-radius: 12px;
      border: none;
      background: #f7fafc;
      color: #4a5568;
      font-weight: 700;
      font-size: 15px;
      cursor: pointer;
      display: flex;
      align-items: center;
      gap: 6px;
      transition: all 0.2s;
    }
    .nav-btn.active {
      background: var(--primary);
      color: white;
      box-shadow: 0 4px 10px rgba(0, 114, 255, 0.3);
    }

    .main-wrap { max-width: 1350px; margin: 22px auto; padding: 0 16px; }
    .tab-content { display: none; }
    .tab-content.active { display: block; }
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

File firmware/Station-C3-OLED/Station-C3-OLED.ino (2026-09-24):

/**
 * @file      Station-C3-OLED.ino
 * @brief     เฟิร์มแวร์เครื่องประจำเตียง รุ่นบอร์ดเล็ก จอ OLED 0.42 นิ้ว
 * @version   1.2.0-C3
 * @date      2026-09-23
 * @author    นายกิตติพันธ์ รัตนคร <kittiphun.rut@mcu.ac.th>
 *
 * @par Organization
 * วิทยาลัยพยาบาลบรมราชชนนี แพร่ คณะพยาบาลศาสตร์ สถาบันพระบรมราชชนก
 * หอผู้ป่วยอายุรกรรม โรงพยาบาลสูงเม่น จังหวัดแพร่
 * อาจารย์ที่ปรึกษา ดร.กรรณิการ์ กาศสมบูรณ์
 *
 * @par Hardware
 * ESP32-C3 Super Mini + จอ OLED 0.42" (SSD1306 I2C 72x40)
 * TCRT5000 AO -> GPIO 4 · ตัวแบ่งแรงดันแบตเตอรี่ -> GPIO 0
 * ออดแบบมีวงจรกำเนิดเสียงในตัว -> GPIO 3 · ปุ่มกด -> GPIO 7
 * จอ OLED I2C -> SCL GPIO 6, SDA GPIO 5
 *
 * @par Description
 * ปรับปรุงจากไฟล์ `ESP32-C3-Station-V_4_4_2.ino` ให้เข้ากับระบบรุ่นปัจจุบัน
 * ของเดิมคุยกับ Host รุ่นนี้ไม่ได้เลย เพราะ `struct_message` เป็น 14 ไบต์
 * ขณะที่ Protocol v3 ต้องเป็น 23 ไบต์ Host จึงทิ้งแพ็กเก็ตตั้งแต่ต้น
 * คงผังขาเดิมของบอร์ดไว้ทุกขา ไม่ต้องแก้สายที่ประกอบไว้แล้ว
 *
 * @par Revision History
 * | Version | Date | Change |
 * |---|---|---|
 * | 1.2.0-C3 | 2026-09-24 | เพิ่มตัวช่วยคาลิเบรตสี่ขั้นตอนที่หน้าเครื่อง วัดทิศสัญญาณเอง และบันทึกสิ่งที่เรียนรู้ลง NVS |
 * | 1.1.0-C3 | 2026-09-23 | จำนวนหยดสะสมรอดการรีบูตและไฟดับแล้ว และเพิ่มสุนัขเฝ้าบ้านกันเครื่องค้างเงียบ |
 * | 1.0.0-C3 | 2026-09-23 | สร้างสายใหม่จากไฟล์ v4.4.2 เดิม ปรับเป็น Protocol v3 ไล่หาช่องสัญญาณเอง ใช้ `drop_detector.h` ตัวเดียวกับสายหลัก และออกแบบหน้าจอ 72x40 ใหม่ทั้งหมด |
 *
 * @warning  ไฟล์วาดจอถูก `#include` ท้ายไฟล์นี้ก่อน `setup()` ห้ามย้ายขึ้นไปบนสุด
 *           เพราะโค้ดในไฟล์นั้นใช้ตัวแปรและฟังก์ชันช่วยที่ประกาศไว้ด้านบน
 *
 * @warning  `struct_message` และ `struct_host_sync` ต้องเหมือนกันทุกไบต์ในทุกเฟิร์มแวร์
 *           ตรวจด้วย `bash tools/protocol-test/run.sh` ก่อน commit ทุกครั้งที่แตะโครงสร้างนี้
 *
 * @warning  ยังไม่ได้ทดสอบบนฮาร์ดแวร์จริง ตรวจด้วยเครื่องมือจำลองบนเครื่อง PC เท่านั้น
 *
 * @par บันทึกการเปลี่ยนแปลงโดยละเอียด
 * เก็บข้อความเดิมไว้ทั้งหมด เพราะเหตุผลเชิงเทคนิคในนั้นหาจากที่อื่นไม่ได้
 *  ที่มา: ปรับปรุงจากเฟิร์มแวร์ ESP32-C3 v4.4.2 ให้เข้ากับระบบรุ่นปัจจุบัน
 *
 *  ของเดิมคุยกับ Host รุ่นปัจจุบัน "ไม่ได้เลย" เพราะโครงสร้างแพ็กเก็ตคนละแบบ
 *
 *    ของเดิม  struct_message   14 ไบต์   ไม่มี flowRateHr / msSinceLastDrop / flags
 *    ของเดิม  struct_time_sync  5 ไบต์   Host รุ่นปัจจุบันส่ง struct_host_sync 20 ไบต์
 *
 *  รุ่นนี้ใช้ Protocol v3 ครบถ้วน จึงเสียบเข้าระบบเดิมได้ทันทีโดยไม่ต้องแก้ฝั่ง Host
 *
 *  สิ่งที่แก้จาก v4.4.2 เรียงตามความสำคัญ
 *
 *   1) โครงสร้างแพ็กเก็ตเป็น Protocol v3 (23/20 ไบต์) พร้อม static_assert กันพลาด
 *      รับค่า dropFactor, targetRateHr, totalPlanMl, alertCode, nearEndPct จาก Host
 *      ของเดิมตรึง drop factor ไว้ที่ 20 ในโค้ด เปลี่ยนตามแผนการรักษาไม่ได้
 *
 *   2) การหาช่องสัญญาณ ของเดิมสแกนหา SSID ครั้งเดียวตอนบูตแล้วตรึงช่องไว้
 *      ถ้า Host ย้ายช่อง (ซึ่งเกิดแน่เมื่อ Host ไปเกาะเราเตอร์ตั้งแต่ v4.7.6)
 *      เครื่องจะเงียบตลอดไปจนกว่าจะรีเซ็ต รุ่นนี้ไล่หาช่อง 1-13 เองเมื่อไม่ได้ยิน Host
 *      แล้วจำช่องที่เจอลง NVS เหมือนสายหลัก อย่างช้าที่สุด 32.5 วินาทีก็กลับมาออนไลน์
 *
 *   3) เสียงออดของเดิมใช้ delay() ระหว่างส่งเสียงลูปหยุดทั้งเครื่อง ตรวจจับหยดไม่ทัน
 *      (เสียงยืนยันตอนคาลิเบรตยาวถึง 800 ms) รุ่นนี้เป็นคิวจังหวะแบบไม่บล็อก
 *
 *   4) สูตรอัตราการไหล ของเดิมนับหยดในหน้าต่าง 2.5 วินาทีแล้วคูณขึ้นเป็นต่อนาที
 *      ที่ 20 หยด/นาที หน้าต่างนั้นมีหยดเฉลี่ยไม่ถึง 1 หยด ตัวเลขจึงกระโดด 0-48
 *      รุ่นนี้ใช้หน้าต่างสะสม 8 หยดแบบเดียวกับสายหลัก (แก้ความลำเอียงของ Jensen)
 *
 *   5) ตัวตรวจจับหยดใช้ drop_detector.h ตัวเดียวกับสายหลัก เรียนรู้รูปคลื่นหยดเองได้
 *      และตั้งแต่ v1.2.0-C3 มีตัวช่วยคาลิเบรตสี่ขั้นตอนไว้ตรวจว่าวางเซนเซอร์ถูกที่
 *      ของเดิมใช้เกณฑ์คงที่ + ฮิสเทอรีซิส ซึ่งถุงแกว่งตอนคนไข้เดินก็นับเป็นหยด
 *
 *   6) เลขเตียงตั้งที่หน้าเครื่องแล้วจำลง NVS ของเดิมต้องแก้ #define แล้วคอมไพล์ใหม่
 *      ทีละเตียง ซึ่งใช้จริงในหอผู้ป่วยไม่ไหว
 *
 *   7) หน้าจอออกแบบใหม่ทั้งหมดสำหรับ 72x40 ดูหัวข้อในไฟล์ StationScreen.h
 *
 *  การต่อสาย (คงผังขาเดิมของบอร์ด v4.4.2 ไว้ทุกขา)
 *    TCRT5000 AO   -> GPIO 4  (ADC1_CH4)
 *    ตัวแบ่งแรงดันแบตเตอรี่ -> GPIO 0  (ADC1_CH0)
 *    ออดแบบมีวงจรกำเนิดเสียงในตัว -> GPIO 3  (สั่งงานด้วยลอจิกสูง)
 *    ปุ่มกด        -> GPIO 7  (ต่อลงกราวด์ ใช้ตัวต้านทานพูลอัพในตัว)
 *    จอ OLED I2C   -> SCL GPIO 6, SDA GPIO 5
 *
 *  ข้อจำกัด: ยังไม่ได้ทดสอบบนฮาร์ดแวร์จริง ตรวจด้วยเครื่องมือจำลองบน PC เท่านั้น
 */

#include <WiFi.h>
#include <esp_now.h>
#include <esp_wifi.h>
#include <U8g2lib.h>
#include <Wire.h>
#include <Preferences.h>
#include <time.h>
#include <sys/time.h>
#include <math.h>
#include <esp_task_wdt.h>          // [1.1.0-C3] เพิ่ม: สุนัขเฝ้าบ้าน กันเครื่องค้างเงียบ
#include <esp_system.h>            // [1.1.0-C3] เพิ่ม: อ่านสาเหตุการรีบูตครั้งล่าสุด
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

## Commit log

2026-09-12 station: redesign TFT UI (IV BAG concept) + 30-min flow trend page
    Station v7.4.0 -> v7.5.0 (เปลี่ยนเฉพาะส่วนแสดงผล ตรรกะและ Protocol v3 เหมือนเดิม)
    - หน้าหลักใหม่แนวทาง IV BAG: ภาพถุงน้ำเกลือที่ระดับน้ำลดลงจริงตามปริมาณที่ให้ไปแล้ว
    กระเปาะหยดมีภาพหยดตกตามหยดจริง และเหลือตัวเลขสำคัญ 4 ค่า
    (อัตราไหล / ปริมาณคงเหลือ / เว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
    [driver.cpp]
2026-09-12 fix(firmware): ย้ายการประกาศ enum/struct ขึ้นต้นไฟล์ ให้ Arduino IDE คอมไพล์ผ่าน
    Arduino IDE สร้าง prototype ของทุกฟังก์ชันแล้วแทรกไว้ก่อนฟังก์ชันแรกของไฟล์ .ino
    ชนิดข้อมูลที่ประกาศไว้กลางไฟล์จึงทำให้ขึ้น error ว่า 'XXX does not name a type'
    (ไม่เจอตอนตรวจด้วย g++ เพราะคอมไพล์เป็น .cpp ธรรมดาที่ไม่มีการแทรก prototype)
    -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
2026-09-12 host(touch): เพิ่มนาฬิกา DS3231 และบันทึกข้อมูลลงการ์ด SD (v4.9.1-TOUCH)
    เวลา/วันที่
    - อ่านเวลาจาก DS3231 ตอนเปิดเครื่อง ถ้าใช้ได้ถือว่าเวลาถูกต้องทันที
    ไม่งั้นค่อยตกไปใช้ค่าสำรองใน NVS แล้วรอเวลาจากหน้าเว็บ
    - เมื่อสมาร์ตโฟนส่งเวลามาทาง POST /api/time/set จะเขียนลง DS3231 ให้ด้วย
    - เทียบเวลาระ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
2026-09-12 แก้สูตรคำนวณอัตราการไหลและบั๊กฝั่ง Host (Station 7.7.3/7.5.4, Host 4.7.5)
    จากการตรวจสอบหลักการคำนวณทั้งฝั่ง Station และ Host พบปัญหา 4 จุด
    Station v7.7.3 และ v7.5.4 — สูตรอัตราการไหล
    ของเดิมเฉลี่ย "อัตราขณะนั้น" (60000/dt) แบบถ่วงน้ำหนัก 0.75 ซึ่งเป็นการเฉลี่ย
    ส่วนกลับของเวลา ทำให้ (1) ค่าเอนสูงเสมอตามอสม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
2026-09-12 host(oled): รองรับ Station v7.5.1 และ v7.7.0 + เตือนเซนเซอร์ยังไม่จับหยด (v4.7.1-OLED)
    ตรวจความเข้ากันได้ก่อน: โครงสร้างแพ็กเก็ต ESP-NOW ของ Station v7.5.1 และ v7.7.0
    เหมือน v7.4.x ทุกไบต์ (struct_message 23 / struct_host_sync 20) สูตรตัดสินสายพับ
    ก็สูตรเดียวกัน จึงใช้งานร่วมกันได้อยู่แล้วโดยไม่ต้องแก้โปรโตคอล
    เพิ่ม tools/protocol-test ที่ด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
2026-09-12 station: แก้ตัวตรวจจับค้างที่เฟสรอนิ่งจนไม่นับหยด (v7.5.1)
    อาการที่พบหน้างาน: ในขั้นที่ 2 ของการคาลิเบรต กราฟขึ้นแท่งเหลืองตามจังหวะหยดจริง
    แต่ตัวเลขไม่นับเลย
    สาเหตุ: แท่งเหลืองบนกราฟระบายสีจาก sensorDelta เทียบกับเกณฑ์โดยตรง ไม่เกี่ยวกับ
    เครื่องจักรสถานะ ส่วนการ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
2026-09-12 station: รองรับเซ็นเซอร์หยดแบบเอาต์พุตดิจิทัล + ผังขาใหม่ (v7.6.0)
    เซ็นเซอร์ตัวใหม่มีวงจรเปรียบเทียบในตัว ให้พัลส์ Active HIGH 1 พัลส์ต่อ 1 หยด
    จึงเปลี่ยนวิธีตรวจจับจากการอ่าน ADC ทุกรอบ loop มาเป็นการรับขัดจังหวะที่ขอบขาขึ้น
    ผังขาใหม่ (จัดกลุ่มมาอยู่ติดกับบล็อกจอ 8-13 และเ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
2026-09-12 Host v4.7.3 + Station v7.7.2/v7.5.3: แก้อาการ Host ขึ้น OFFLINE เมื่อมีหลายเตียง
    สาเหตุ (วัดได้ด้วย tools/link-sim): ทุกสเตชันส่งทุก 1000 ms เป๊ะ ไม่มีการสุ่ม
    คริสตัลสองบอร์ดต่างกัน ~40 ppm = คาบเลื่อนหากันเพียง 0.04 ms ต่อวินาที
    เมื่อสองเตียงส่งห่างกันไม่ถึงความยาวเฟรม (~0.8 ms) จะชนกันค้างราว 40 วินาที
    ซึ่งนานก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
2026-09-12 station: แก้การวาดกราฟทำให้ไม่นับหยด + เรียนรู้หยดต่อเนื่อง + กันถุงแกว่ง (v7.5.1)
    สาเหตุจริงของอาการ "กราฟเหลืองทะลุเส้นส้มแล้วแต่ไม่นับ"
    การวาดแถบกราฟทั้งแถบบนจอจริงใช้เวลาหลายสิบมิลลิวินาที ซึ่งเกิน
    SENSOR_GAP_RESYNC_MS (25 ms) โค้ดจึงถือว่าอ่านขาดช่วงแล้วตั้งต้นสายสัญ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
2026-09-12 station: รื้อระบบคัดกรองหยดและหน้าคาลิเบรตใหม่ (v7.5.1)
    ต่อยอดจาก v7.5.0 โดยแก้เฉพาะการตรวจจับหยด หน้าจอ/ESP-NOW/การแจ้งเตือนเหมือนเดิมทุกไบต์
    สาเหตุของอาการอ่านเบิ้ล
    ตัวกันสัญญาณรัวเดิม เมื่อค่าต่ำกว่าเกณฑ์แต่ยังไม่พ้น 55 ms จะไม่นับ แต่ก็ไม่ตั้ง
    dropState ตัวจับจึงยังง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
2026-09-12 station: ไม่ต้องคาลิเบรตด้วยมืออีกต่อไป (v7.7.0)
    พยาบาลแค่หนีบเซนเซอร์แล้วเปิดโรลเลอร์ เครื่องเรียนรู้เองภายในไม่กี่หยดแล้วขึ้น READY
    ไม่มีเมนู ไม่มีขั้นตอน ไม่ต้องหยุดน้ำเพื่อวัดอะไรทั้งสิ้น
    สถานะบนจอเหลือ 4 แบบที่อ่านแล้วรู้ว่าต้องทำอะไรต่อ
    STARTING / LEARNING / READY / CHECK S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
2026-09-12 host: new 2.8" TFT build (v4.8.0-TFT) with FOCUS dashboard
    เปลี่ยนจอของเครื่อง Host จาก OLED 1.3" ขาวดำ เป็นจอสี TFT 2.8" (ST7789V 240x320)
    ใช้แนวนอน 320x240 ตามแบบ FOCUS ที่เลือกไว้ ตรรกะและ Protocol v3 เหมือน v4.7.0 ทุกประการ
    - ตัดไลบรารี U8g2 ออกทั้งหมด ใช้ Adafruit GFX + ST7789 แทน (รองรับจอ TFT อย่างเดียว)
    - หน้าหลัก FOCUS: ครึ่งซ้ายเป็นเตียงที่ต้องดูตอนนี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
2026-09-12 host: touch-screen build v4.9.0-TOUCH (2.4" 240x320 + XPT2046)
    เฟิร์มแวร์ Host รุ่นใหม่ที่ใช้จอสัมผัส 2.4 นิ้วแนวตั้ง และออกแบบการใช้งานแบบสมาร์ตโฟน
    ตรรกะการวัด การแจ้งเตือน ESP-NOW (Protocol v3) และหน้าเว็บเหมือน v4.8.0 ทุกประการ
    - หน้าหลักแบบ FOCUS: เตียงที่ต้องดูตอนนี้อยู่บนสุด + รายการเตียงอื่น แตะที่ใดก็เข้าด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
2026-09-12 Station v7.7.1: หมุนจอ 180 องศาได้ที่หน้าเครื่อง
    ตอนติดตั้งจริง ทิศที่สายเซนเซอร์และสาย USB ออกจากกล่องเป็นตัวกำหนดท่าวาง
    บางตำแหน่งวางแล้วจอกลับหัว เดิมต้องแก้โค้ดแล้วแฟลชใหม่
    - เพิ่ม TFT_ROT_NORMAL / TFT_ROT_FLIP180 / TFT_ROTATION_DEFAULT
    - applyScreenRotation() + จำค่าไว้ใน NVS (คีย์ "rot") โหลดตอนเปิดเครื่อง
    - หน้า SET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
2026-09-21 เพิ่มผังการเชื่อมต่ออุปกรณ์ KiCad 7 ของ Station และ Host OLED
    รีโพยังไม่เคยมีเอกสารฮาร์ดแวร์เลย ชุดนี้เป็นชิ้นแรก
    hardware/
    Station-BedNode.kicad_sch เครื่องประจำเตียง v7.7.3
    ESP32-S3 Super Mini, จอ TFT ST7789 1.47 นิ้ว, เซนเซอร์ TCRT5000,
    บัซเซอร์ Passive, ปุ่มผู้ใช้
    Host-OLED.kicad_sch เครื่องศูนย์กลาง v4.7.5-OLED
    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
    [Host-OLED.kicad_sch, Station-BedNode.kicad_sch]
2026-09-21 เพิ่มแผ่นวงจรพิมพ์แบบ carrier board ของ Station และ Host OLED
    ต่อยอดจากผัง schematic เดิม เป็นบอร์ดรอง 2 ชั้น รูทะลุทั้งหมด ไม่มีชิ้นส่วน SMD
    โมดูลสำเร็จรูปเสียบลงหัวต่อ บัดกรีด้วยมือได้และถอดเปลี่ยนโมดูลที่เสียได้
    Station-BedNode.kicad_pcb บอร์ดเครื่องประจำเตียง 100 x 86 มม.
    Host-OLED.kicad_pcb บอร์ดเ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
    [Host-OLED-B_Cu.gbl, Host-OLED-B_Mask.gbs, Host-OLED-B_Silkscreen.gbo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]
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
